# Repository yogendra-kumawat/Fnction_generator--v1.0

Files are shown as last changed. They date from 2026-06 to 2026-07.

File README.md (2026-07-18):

# ⚡ Function_generator v1.0 — Power & Control Board







> Battery-powered portable oscilloscope — power management, voltage regulation, user control interface board, and STM32-based firmware with real-time waveform generation and display.

---

## 📋 Overview

This project is a **portable open-source Function_generator** built around the STM32F103 microcontroller. It combines:

- Safe **Li-ion battery charging** from an external USB/DC source
- A clean **regulated voltage rail** for the microcontroller (MCU)
- **Control switches** for power on/off and user interaction
- Protection and filtering circuitry for stable operation
- **Real-time waveform generation** with adjustable frequency and duty cycle **{PWM ,DC,Square}->{working for sine,triangular,and oscilloscopic function}**
- **Dual-channel ADC signal acquisition** with interrupt-driven sampling
- **SSD1306 OLED display** with a multi-window navigation menu
- **FreeRTOS / CMSIS-OS2** multitasking firmware

---

## 🔲 System Block Diagram

```
┌─────────────┐     ┌──────────────┐     ┌─────────────┐
│  USB / DC   │────▶│  Battery     │────▶│  Li-ion /   │
│  Input (5V) │     │  Charger IC  │     │  LiPo Cell  │
└─────────────┘     └──────────────┘     └──────┬──────┘
                                                 │
                                                 ▼
                    ┌──────────────┐     ┌───────────────┐
                    │   STM32F103  │◀────│   Voltage     │
                    │   (MCU)      │     │   Regulator   │
                    └──────┬───────┘     └───────────────┘
                           │
          ┌────────────────┼────────────────┐
          ▼                ▼                ▼
   ┌─────────────┐  ┌────────────┐  ┌─────────────┐
   │ ADC1 / ADC2 │  │ TIM1 / TIM2│  │ SSD1306     │
   │ Signal In   │  │ PWM Out    │  │ OLED (I2C)  │
   └─────────────┘  └────────────┘  └─────────────┘
          ▲
   ┌─────────────┐
   │  Control    │
   │  Switches   │
   │ (EXTI GPIO) │
   └─────────────┘
```

---

## 🧩 Key Hardware Components

| Module | Function | Interface | Type |
|---|---|---|---|
| **Battery Charger IC** | CC/CV Li-ion charging; over-voltage & over-current protection | USB / DC jack | Power |
| **Li-ion / LiPo Cell** | Main energy storage; powers device off-grid | JST connector | Power |
| **Voltage Regulator** | Converts battery voltage to stable 3.3 V / 5 V for MCU | EN pin (switch-controlled) | Regulation |
| **Power Switch** | Hard on/off; drives regulator enable to cut standby draw | Mechanical toggle | Control |
| **Mode / Select Switch** | User input for menu navigation; connects to MCU GPIO via EXTI | MCU GPIO (EXTI2/3) | Control |
| **SSD1306 OLED** | 128×32 display for menus, waveform preview, freq & duty info | I2C (I2C1, 100 kHz) | Display |
| **Decoupling Capacitors** | Filters noise on power rails; stabilises regulator output | Inline on VCC / GND | Passive |

---

## ⚙️ Electrical Specifications

| Parameter | Value |
|---|---|
| Input Voltage | 5 V (USB / DC) |
| Battery Type | Li-ion / LiPo |
| Battery Voltage | 3.7 V nominal |
| Regulated Output | 3.3 V / 5 V |
| Max Charge Current | 500 mA (configurable) |
| MCU | STM32F103 @ 48 MHz (HSE × PLL ×6) |
| ADC Resolution | 12-bit (0–4095) |
| ADC Channels | ADC1 — CH0 (coarse), ADC2 — CH1 (fine) |
| PWM Output | TIM1 CH2 (variable freq + duty) |
| UART | USART1 @ 9600 baud |

---

## 🖥️ Firmware Architecture

The firmware runs on **FreeRTOS / CMSIS-OS2** with four concurrent tasks:

| Task | Priority | Role |
|---|---|---|
| `wave_gen` | Normal | Applies selected waveform output via `set_wave()` |
| `read_wave` | Normal | Reserved for signal acquisition / processing |
| `display` | Low | Drives SSD1306 OLED menu and waveform preview |
| `monitor` | Realtime | Polls ADC via interrupt, handles button EXTI events |

### Clock Configuration

```
HSE (external crystal)
  └──▶ PLL ×6 → 48 MHz SYSCLK
         ├── AHB  /1 → 48 MHz
         ├── APB1 /2 → 24 MHz  (TIM2, I2C)
         ├── APB2 /1 → 48 MHz  (TIM1, ADC)
         ├── ADC  /6 →  8 MHz
         └── USB      → 48 MHz (direct PLL)
```

---

## 📟 Display Menu System

The OLED display (`window` variable) has five screens:

| Window | Screen | Description |
|---|---|---|
| `0` | **Main Menu** | Scrollable list — Waves, Oscill., Port, PWM, Config |
| `1` | **Wave Select** | Choose waveform type: Sine, Ramp, Square, Noise, DC |
| `3` | **Port Select** | Choose output port: A or B |
| `4` | **PWM Control** | Live freq + duty cycle adjust with waveform preview |
| `5` | **Config** | Register/settings placeholder |

Navigation uses two buttons:
- **SELECT\_1** (`EXTI2`) — scroll / increment selection
- **SELECT\_2** (`EXTI3`) — confirm / enter submenu (toggle `select2`)
## display overview
WhatsApp Video 2026-06-03 at 1 54 03 PM
WhatsApp Video 2026-06-03 at 1 50 50 PM

---

## 🌊 PWM / Waveform Generation

`set_dynamic_frequency()` computes TIM1 prescaler and auto-reload register values at runtime to hit any target frequency from the 48 MHz timer clock:

```c
uint32_t total_divider = 48_000_000 / target_freq;
uint32_t psc = (total_divider - 1) / 65536;
uint32_t arr = (total_divider / (psc + 1)) - 1;
uint32_t pulse = (duty_cycle * (arr + 1)) / 100;
```

- **Frequency range:** ~1 Hz to ~47 MHz (capped at 47 MHz in MHz mode)
- **Duty cycle:** 0–100%, derived from ADC1 coarse potentiometer
- **Fine frequency:** derived from ADC2 fine potentiometer
- **Frequency units:** selectable — Hz / kHz / MHz (multipliers: ×1 / ×1000 / ×1 000 000)

---

## 🔍 How It Works

### 1 — Battery Charging

When a USB or DC supply is connected, based on feedback from charging battery the power is controlled ,basically turning off the power supply when battery is charged.

### 2 — Regulated Power to MCU

basically is is based on the voltage follower principle.

### 3 — Signal Acquisition (ADC)

Both ADC1 and ADC2 are started in **interrupt mode** (`HAL_ADC_Start_IT`) by the `monitor` task every 300 ms(also to control the bouncing effect of buttons so giving delay ). The `HAL_ADC_ConvCpltCallback` ISR:
- Reads the raw 12-bit value
- Tracks rolling **min / max** for dynamic range normalisation
- Toggles an indicator GPIO (`indi_Pin`) on every conversion

### 4 — Control Switches (EXTI)

`select_1_Pin` and `select_2_Pin` are configured as **falling-edge EXTI** inputs with internal pull-ups. The EXTI callback sets `flag_1` and wakes the `monitor` task via `osThreadFlagsSet`. The monitor task then increments `select1` (0–4) or `select2` (0–1) accordingly.

---

## 🚀 Getting Started

**Step 1 — Connect Battery**  
Connect a Li-ion / LiPo cell to the JST battery connector, observing polarity markings on the PCB silkscreen.

**Step 2 — (Optional) Charge**  
Connect a 5 V USB or DC supply. The onboard charging IC will manage the charge cycle automatically. The charge LED illuminates during active charging.

**Step 3 — Flash Firmware**  
Open the project in **STM32CubeIDE**{extract the file and arrange accordigly in stm ide as due to version conflicts the direct project will not work }.
see main.c file for full logic implementation

**Step 4 — Power On**  
Flip the power switch to **ON**. The voltage regulator enables, the MCU boots, and the OLED displays the main menu.

**Step 5 — Navigate**  
- Press **SELECT\_1** to scroll through menu items.
- Press **SELECT\_2** to enter a submenu.
- In **PWM mode** (Window 4): rotate the coarse pot (ADC1) to adjust duty cycle; rotate the fine pot (ADC2) to adjust frequency. Press SELECT\_1 to cycle Hz → kHz → MHz.

---

## 🛠️ Dependencies

| Dependency | Purpose |
|---|---|
| STM32CubeIDE / CubeMX | Project generation and build toolchain |
| STM32 HAL (F1 series) | Peripheral abstraction (ADC, TIM, I2C, UART, USB) |
| CMSIS-OS2 / FreeRTOS | RTOS kernel |
| `ssd1306` driver | I2C OLED display library (`ssd1306.h`, `ssd1306_fonts.h`) |{references->https://github.com/afiskon/stm32-ssd1306}

---

## 📄 License

This project is open source. See [`LICENSE`](./LICENSE) for details.

---

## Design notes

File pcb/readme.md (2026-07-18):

# 🟤 Function Generator v1.0 — PCB

## Board Specs

| Property | Value |
|---|---|
| Substrate | Single-sided FR2 copper-clad |
| Fabrication | Toner-transfer chemical etch|
| Copper layer | 1 (bottom) |
| Board size | (90x45 mm) |

<br>

---

## Toner Transfer Etch Process

1. Print copper layer (mirrored) 

2. Cut copper-clad board to size(90x45 mm), clean surface with fine sandpaper + acetone

3. Place paper face-down on copper, press firmly with clothes iron
   Temperature : ~180 °C
   Duration    : 5–7 minutes, firm even pressure, no sliding

4. Soak board in warm water for 2–3 minutes, peel paper slowly
   Toner remains bonded to copper as etch resist

5. Inspect under light — touch up any broken traces with a permanent marker

WhatsApp Image 2026-07-17 at 7 32 57 PM

6. Submerge in FeCl₃ (ferric chloride) solution
   Time : 15–30 min depending on solution temperature and
   stair the solution for fast etching

WhatsApp Video 2026-07-18 at 9 00 03 AM

7. Remove when all unprotected copper is dissolved — only traces remain

8. Rinse thoroughly, strip toner with acetone

WhatsApp Image 2026-07-17 at 7 25 27 PM

9. Dry, inspect continuity with multimeter
---

> **Tip:** Warm FeCl₃ (~40 °C) etches 2× faster and gives cleaner trace edges. A plastic container on a hot plate works fine.

<br>

---

## DIY Drill Rig

No PCB drill press — so one was built.

```
┌─────────────────────────┐
│   Servo Tester Module   │  ← Speed control via PWM knob
│   (blue box, blue LED)  │
└────────────┬────────────┘
             │ PWM signal
             ▼
   Brushless RC Motor
   (gold can, ~12 V)
             │
   Press-fit into PVC pipe  ← Acts as handle + rigidity
             │
   Keyless Mini Drill Chuck
             │
    0.8 mm Carbide Drill Bit
```

WhatsApp Image 2026-07-17 at 7 33 01 PM

<br>

---

## What's On the Board

### Power Section
- ams1117-adj — adjustable output regulator
- ams1117-5.0 — fixed 5 V
- AMS1117-3.3 — fixed 3.3 V
- Li-Ion charging IC (TP4056-style)
- DC barrel jack for external input

### Signal Section
- ADC input pin headers (2 channels, dual-simultaneous)
- 10 Ω on input limits current on accidental short — protects regulators from latch-up

### User Interface
- 4× tactile switches (6×6 mm)
- 2× trimmer potentiometers (10 kΩ)
- 1× green LED (power indicator)

### Connectors
- I²C header (GND / VCC / SCL / SDA) — for SSD1306 OLED
- extra I²C port for future use
- STM32 Blue Pill debugging wires via male pin headers
- other useful pin headers
<br>


<br>
WhatsApp Image 2026-07-17 at 7 25 34 PM
WhatsApp Image 2026-07-17 at 7 25 36 PM

---

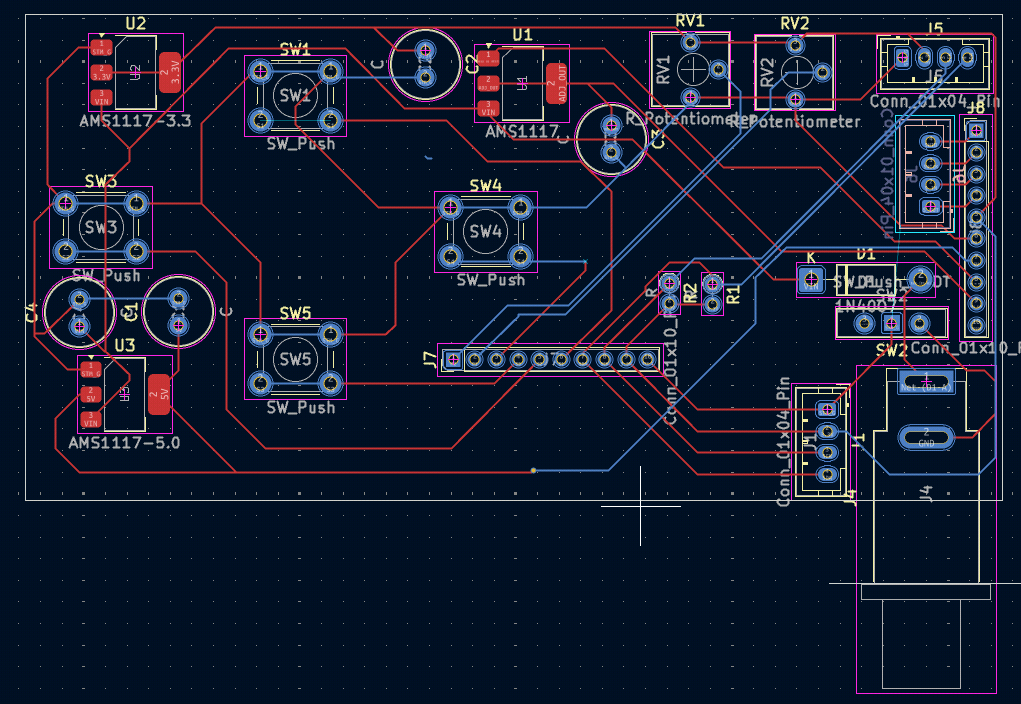
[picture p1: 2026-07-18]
pcb/pcb.png

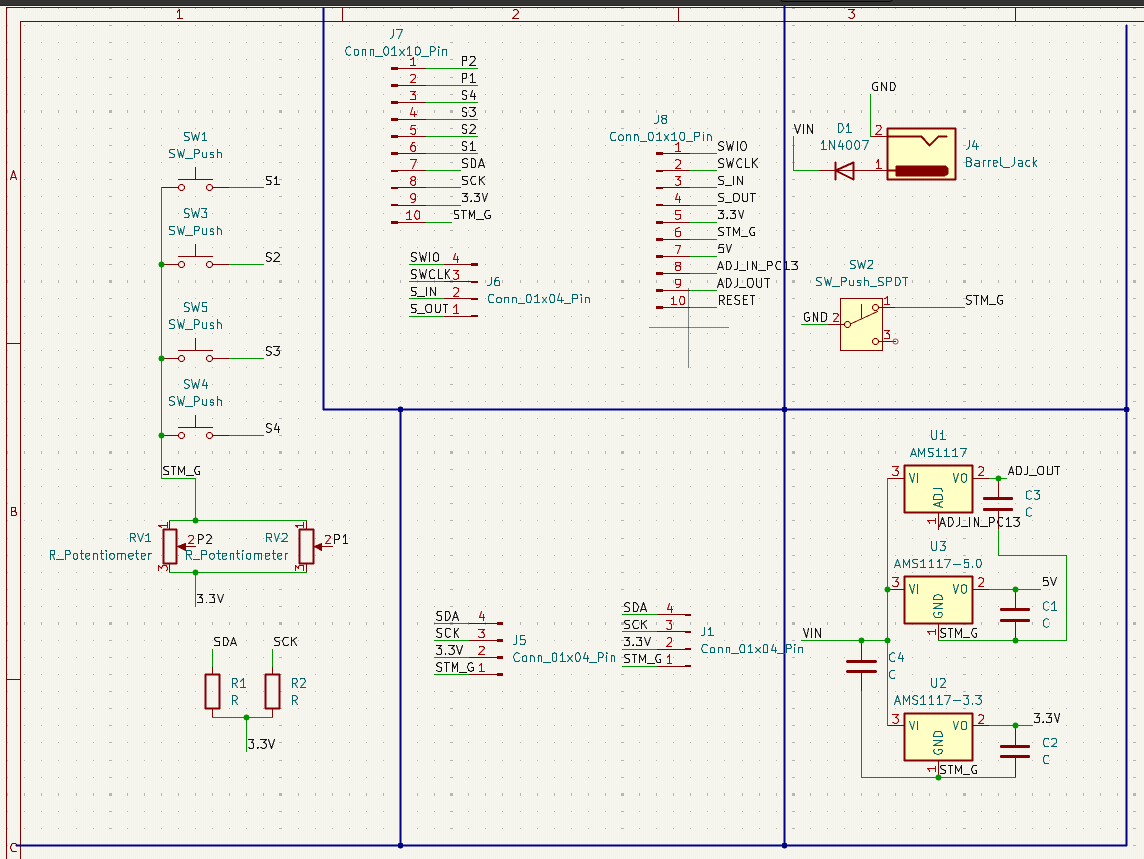
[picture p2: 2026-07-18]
pcb/sch.png

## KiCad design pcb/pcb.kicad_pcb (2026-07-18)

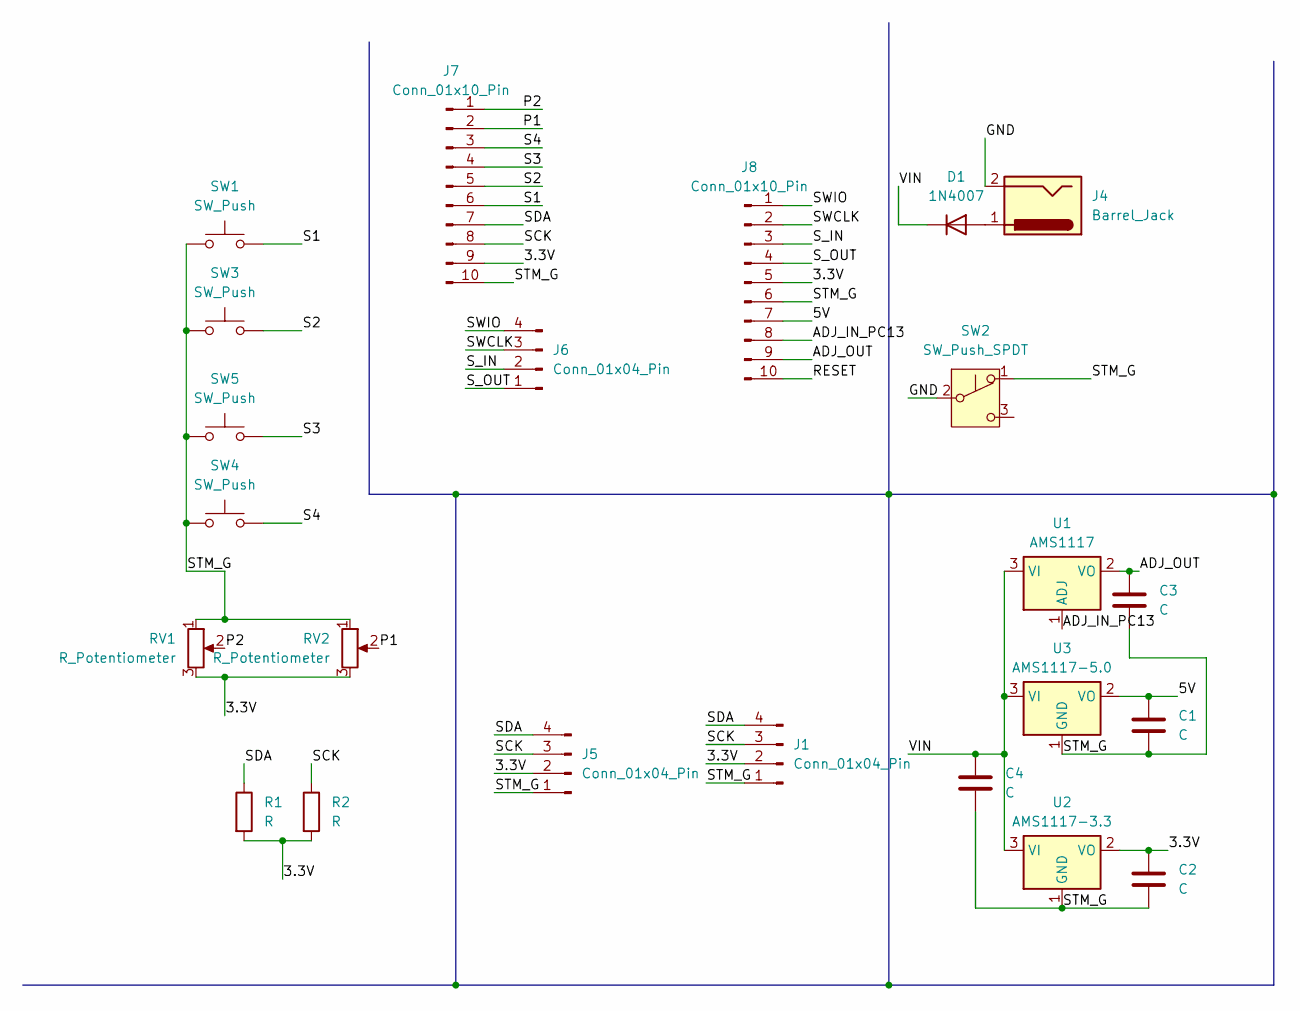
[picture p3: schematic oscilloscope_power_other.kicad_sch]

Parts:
C1, C2, C3, C4: C; C_Radial_D6.3mm_H11.0mm_P2.50mm
D1: 1N4007; D_DO-41_SOD81_P10.16mm_Horizontal
J1, J5, J6: Conn_01x04_Pin; JST_PH_B4B-PH-K_1x04_P2.00mm_Vertical
J4: Barrel_Jack; BarrelJack_SwitchcraftConxall_RAPC10U_Horizontal
J7, J8: Conn_01x10_Pin; PinHeader_1x10_P2.00mm_Vertical
R1, R2: R; R_Axial_DIN0204_L3.6mm_D1.6mm_P1.90mm_Vertical
RV1, RV2: R_Potentiometer; Potentiometer_Vishay_T73YP_Vertical
SW1, SW3, SW4, SW5: SW_Push; SW_PUSH-12mm
SW2: SW_Push_SPDT; SW_Slide-03_Wuerth-WS-SLTV_10x2.5x6.4_P2.54mm
U1: AMS1117; SOT-223-3_TabPin2
U2: AMS1117-3.3; SOT-223-3_TabPin2
U3: AMS1117-5.0; SOT-223-3_TabPin2

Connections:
/3.3V: C2.1, J1.2, J5.2, J7.9, J8.5, R1.2, R2.2, RV1.3, RV2.3, U2.2 (VO)
/5V: C1.1, J8.7, U3.2 (VO)
/ADJ_IN_PC13: J8.8, U1.1 (ADJ)
/ADJ_OUT: C3.1, J8.9, U1.2 (VO)
/GND: J4.2, SW2.2 (B)
/P1: J7.2, RV2.2
/P2: J7.1, RV1.2
/RESET: J8.10
/S1: J7.6, SW1.2
/S2: J7.5, SW3.2
/S3: J7.4, SW5.2
/S4: J7.3, SW4.2
/SCK: J1.3, J5.3, J7.8, R2.1
/SDA: J1.4, J5.4, J7.7, R1.1
/STM_G: C1.2, C2.2, C3.2, C4.2, J1.1, J5.1, J7.10, J8.6, RV1.1, RV2.1, SW1.1, SW2.1 (A), SW3.1, SW4.1, SW5.1, U2.1 (GND), U3.1 (GND)
/SWCLK: J6.3, J8.2
/SWIO: J6.4, J8.1
/S_IN: J6.2, J8.3
/S_OUT: J6.1, J8.4
/VIN: C4.1, D1.1 (K), U1.3 (VI), U2.3 (VI), U3.3 (VI)
unnamed: D1.2 (A), J4.1

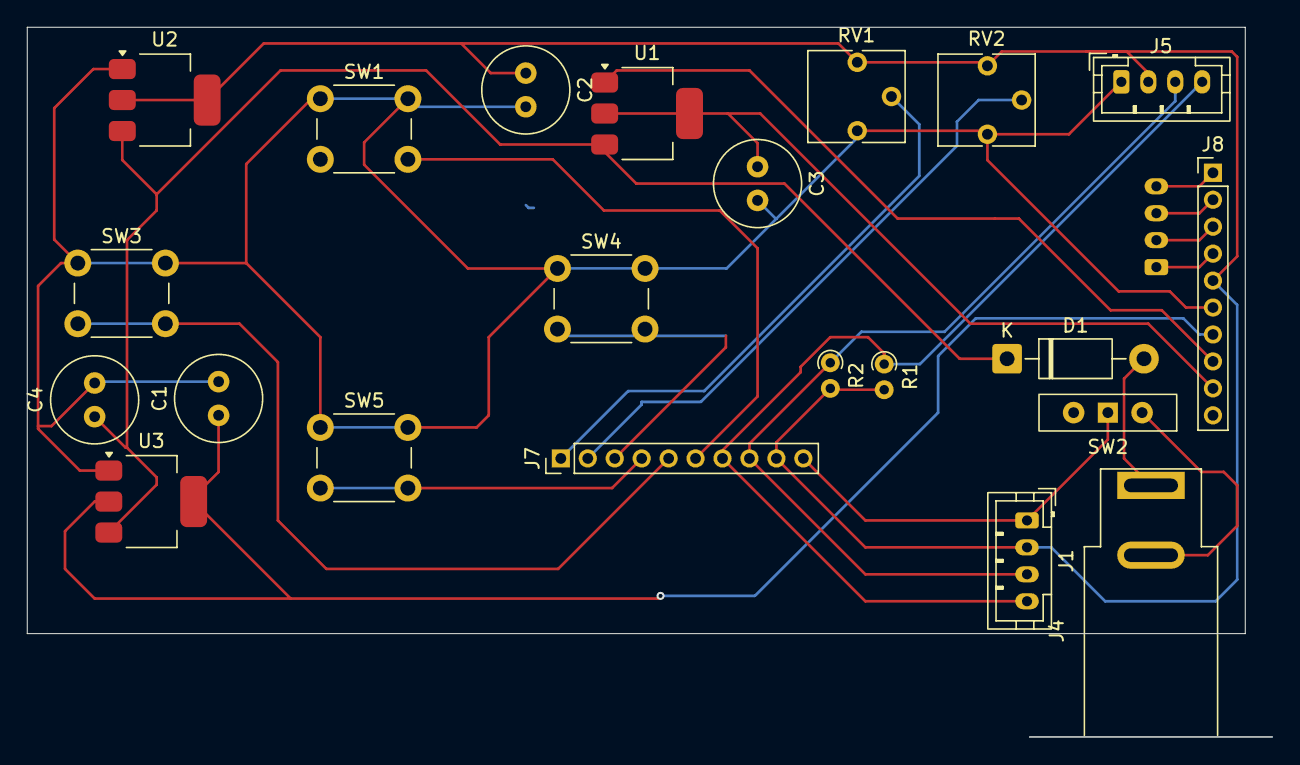
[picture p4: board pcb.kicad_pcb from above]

Board: 2 copper layers, 90.4 x 45.0 mm, 23 parts (1 on the bottom side), 20 nets.

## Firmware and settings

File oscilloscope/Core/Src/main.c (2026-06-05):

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
/* Includes ------------------------------------------------------------------*/
#include "main.h"
#include "cmsis_os.h"

/* USER CODE BEGIN Includes */
#include<stdio.h>
#include "ssd1306.h"
#include "ssd1306_fonts.h"
volatile int raw_adc_value1=0;
volatile int raw_adc_value2=0;
uint8_t select1=0;
uint8_t select2=0;
 int fine_max=1;
 int fine_min=9999;
int value_max=1;
 int value_min=9999;
volatile int freq=0;
uint8_t flag_1=0;
uint8_t window=5;
int duty_cycle=80;
  char freq_text[10];
  char duty_cyc[5];
int port=0;
int pwm_log=0;
char slp[5];
int edit=0;
char channel='T';
uint8_t ch_assig=0;
const uint8_t sine_wave[40] = {
    10, 12, 13, 15, 16, 17, 18, 19, 20, 20,
    20, 20, 20, 19, 18, 17, 16, 15, 13, 12,
    10,  8,  7,  5,  4,  3,  2,  1,  0,  0,
     0,  0,  0,  1,  2,  3,  4,  5,  7,  8
};
/* USER CODE END Includes */

ADC_HandleTypeDef hadc1;
ADC_HandleTypeDef hadc2;

I2C_HandleTypeDef hi2c1;

TIM_HandleTypeDef htim1;
TIM_HandleTypeDef htim2;

UART_HandleTypeDef huart1;

PCD_HandleTypeDef hpcd_USB_FS;

/* Definitions for wave_gen */
osThreadId_t wave_genHandle;
const osThreadAttr_t wave_gen_attributes = {
  .name = "wave_gen",
  .stack_size = 128 * 4,
  .priority = (osPriority_t) osPriorityNormal,
};
/* Definitions for read_wave */
osThreadId_t read_waveHandle;
const osThreadAttr_t read_wave_attributes = {
  .name = "read_wave",
  .stack_size = 128 * 4,
  .priority = (osPriority_t) osPriorityNormal,
};
/* Definitions for display */
osThreadId_t displayHandle;
const osThreadAttr_t display_attributes = {
  .name = "display",
  .stack_size = 128 * 4,
  .priority = (osPriority_t) osPriorityLow,
};
/* Definitions for monitor */
osThreadId_t monitorHandle;
const osThreadAttr_t monitor_attributes = {
  .name = "monitor",
  .stack_size = 128 * 4,
  .priority = (osPriority_t) osPriorityRealtime,
};
/* USER CODE BEGIN PV */

void set_dynamic_frequency(uint32_t target_freq ,int duty)
{
    if (target_freq == 0) return;

    uint32_t timer_clock = 48000000; // 48 MHz base clock
    uint32_t total_divider = timer_clock / target_freq;
    uint32_t psc = (total_divider - 1) / 65536;

     uint32_t arr = (total_divider / (psc + 1)) - 1;

     __HAL_TIM_SET_PRESCALER(&htim1, psc);
    __HAL_TIM_SET_AUTORELOAD(&htim1, arr);

    uint32_t dynamic_pulse = (duty * (arr + 1)) /100;
    __HAL_TIM_SET_COMPARE(&htim1, TIM_CHANNEL_2, dynamic_pulse);
}
//getting control signal using interrupts

void HAL_ADC_ConvCpltCallback(ADC_HandleTypeDef* hadc)
{
    if(hadc->Instance == ADC1)
    {
    	raw_adc_value1 = HAL_ADC_GetValue(&hadc1);
    	 		          if (value_max<raw_adc_value1)
    	 		        	 value_max=raw_adc_value1;
    	 		         if (value_min>raw_adc_value1)
    						 value_min=raw_adc_value1;
    }
    else if (hadc->Instance==ADC2)

    { raw_adc_value2 = HAL_ADC_GetValue(&hadc2);
	   if (fine_max<raw_adc_value2)
				 fine_max=raw_adc_value2;
			 if (fine_min>raw_adc_value2)
				 fine_min=raw_adc_value2;

 }
    HAL_GPIO_TogglePin(GPIOC, indi_Pin);

}
void  HAL_GPIO_EXTI_Callback(uint16_t select_1){
	if (select_1==select_1_Pin){
flag_1=1;}
else if (select_1==select_2_Pin){
	flag_1=2;}
	edit=1;
	osThreadFlagsSet(monitorHandle, 0x01);

}



// all control signal geted

void set_wave(int freq,int channel)
{
    switch (channel){
	case 1:
	    __HAL_TIM_SET_COMPARE(&htim1, TIM_CHANNEL_1, freq);
	    break;
	case 2:
		__HAL_TIM_SET_COMPARE(&htim2, TIM_CHANNEL_1, freq);
		break;
      }
}




/* USER CODE END PV */

void SystemClock_Config(void);
static void MX_GPIO_Init(void);
static void MX_ADC1_Init(void);
static void MX_I2C1_Init(void);
static void MX_TIM1_Init(void);
static void MX_TIM2_Init(void);
static void MX_USART1_UART_Init(void);
static void MX_USB_PCD_Init(void);
static void MX_ADC2_Init(void);
void start_wave_gen(void *argument);
void StartRead(void *argument);
void StartDisplay(void *argument);
void StartMonitor(void *argument);

/**
  * @brief  The application entry point.
  * @retval int
  */
int main(void)
{

  /* MCU Configuration--------------------------------------------------------*/

  /* Reset of all peripherals, Initializes the Flash interface and the Systick. */
  HAL_Init();

  /* Configure the system clock */
  SystemClock_Config();

  /* Initialize all configured peripherals */
  MX_GPIO_Init();
  MX_ADC1_Init();
  MX_I2C1_Init();
  MX_TIM1_Init();
  MX_TIM2_Init();
  MX_USART1_UART_Init();
  MX_USB_PCD_Init();
  MX_ADC2_Init();
  /* USER CODE BEGIN 2 */
  HAL_ADCEx_Calibration_Start(&hadc1);
    HAL_ADCEx_Calibration_Start(&hadc2);
    HAL_TIM_PWM_Start(&htim1, TIM_CHANNEL_2);
  /* USER CODE END 2 */

  /* Init scheduler */
  osKernelInitialize();

  /* USER CODE BEGIN RTOS_MUTEX */
  /* add mutexes, ... */

  /* USER CODE END RTOS_MUTEX */

  /* USER CODE BEGIN RTOS_SEMAPHORES */
  /* add semaphores, ... */
  /* USER CODE END RTOS_SEMAPHORES */

  /* USER CODE BEGIN RTOS_TIMERS */
  /* start timers, add new ones, ... */
  /* USER CODE END RTOS_TIMERS */

  /* USER CODE BEGIN RTOS_QUEUES */
  /* add queues, ... */
  /* USER CODE END RTOS_QUEUES */

  /* Create the thread(s) */
  /* creation of wave_gen */
  wave_genHandle = osThreadNew(start_wave_gen, NULL, &wave_gen_attributes);

  /* creation of read_wave */
  read_waveHandle = osThreadNew(StartRead, NULL, &read_wave_attributes);

  /* creation of display */
  displayHandle = osThreadNew(StartDisplay, NULL, &display_attributes);

  /* creation of monitor */
  monitorHandle = osThreadNew(StartMonitor, NULL, &monitor_attributes);

  /* USER CODE BEGIN RTOS_THREADS */
  /* add threads, ... */
  /* USER CODE END RTOS_THREADS */

  /* USER CODE BEGIN RTOS_EVENTS */
  /* add events, ... */
  /* USER CODE END RTOS_EVENTS */

  /* Start scheduler */
  osKernelStart();

  /* We should never get here as control is now taken by the scheduler */

  /* Infinite loop */
  /* USER CODE BEGIN WHILE */
  while (1)
  {
    /* USER CODE END WHILE */

    /* USER CODE BEGIN 3 */
  }
  /* USER CODE END 3 */
}

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
/* USER CODE BEGIN Header_start_wave_gen */
/**
  * @brief  Function implementing the wave_gen thread.
  * @param  argument: Not used
  * @retval None
  */
/* USER CODE END Header_start_wave_gen */
void start_wave_gen(void *argument)
{
  /* USER CODE BEGIN 5 */
  /* Infinite loop */
  for(;;)
  {

	  if (select1==1)
		  if (select1==1||select1==2)
	  set_wave(freq,select1);
    osDelay(1);
  }
  /* USER CODE END 5 */
}

/* USER CODE BEGIN Header_StartRead */
/**
* @brief Function implementing the read_wave thread.
* @param argument: Not used
* @retval None
*/
/* USER CODE END Header_StartRead */
void StartRead(void *argument)
{
  /* USER CODE BEGIN StartRead */
  /* Infinite loop */
  for(;;)
  {
    osDelay(1);
  }
  /* USER CODE END StartRead */
}

/* USER CODE BEGIN Header_StartDisplay */
/**
* @brief Function implementing the display thread.
* @param argument: Not used
* @retval None
*/
/* USER CODE END Header_StartDisplay */
void StartDisplay(void *argument)
{
  /* USER CODE BEGIN StartDisplay */
	ssd1306_Init();
	char wave_menu[5][9]={"Sine","Triangle","Square","Noise","Dc"};
	char menu[5][7]={"Waves","oscill.","port","pwm","config"};
	char ffreq[3][4]={"Hz","Khz","Mhz"};
	int freq_mul[3]={1,1000,1000000};
	char ports[2][2]={"A","B"};

  /* Infinite loop */

	  int scroll=0,temp=0;

   for(;;)
  {
	  if (scroll==0 && select2==1){
	 	  		  window=1;
	 	  	  }
	  if (scroll==1 && select2==1){
	 	 	  		  window=2;
	 	 	  	  }
	  if (scroll==2 && select2==1){
		  window=3;
	  }
	  if (scroll==3 && select2==1){
		  window=4;
	  }
	  if (scroll==4 && select2==1){
		  window=5;
	  }
	  if (ch_assig&&window!=3){
	  	  		if (select1==1)
	  			  channel='B';
	  	    else
	  			  channel='A';
	  	  	}
	  ch_assig=0;
	  duty_cycle=raw_adc_value1*100/(value_max-value_min);//100/(value_max-value_min)*
	  freq=raw_adc_value2*1000/(fine_max-fine_min);
	  sprintf(freq_text, "%d", freq );
	  sprintf(duty_cyc, "%d", duty_cycle);//
	  ssd1306_Fill(Black);
		 ssd1306_Line(80, 0, 80, 31, White);
		 ssd1306_Line(20, 0, 20, 31, White);
		 ssd1306_Line(0, 19, 20, 19, White);

if (pwm_log){
	ssd1306_SetCursor(2, 22);
	  ssd1306_WriteString("pwm",  Font_6x8, White);
}
else {
	ssd1306_SetCursor(1, 0);
		 		  ssd1306_WriteChar('A',  Font_6x8, White);
		 		 ssd1306_SetCursor(2, 11);
				ssd1306_WriteChar('B',  Font_6x8, White);
		 ssd1306_SetCursor(3, 22);
		  ssd1306_WriteString(";)",  Font_7x10, White);
	 ssd1306_Line(0, 9, 20, 9, White);
	 if (channel=='A'){
	ssd1306_FillRectangle(0, 0,20,9, White);
	ssd1306_SetCursor(1, 0);
		  ssd1306_WriteString("A",  Font_6x8, Black);}
	 if (channel=='B'){
			ssd1306_FillRectangle(0, 9,20,20, White);
			ssd1306_SetCursor(2, 11);
		  	ssd1306_WriteString("B",  Font_6x8, Black);
	 }

}


	  if (window==0){
		  scroll=select1;
		  if (select1<3)
	  	  temp=select1;
	  	 for(int i=0;i<3;i++){
	  				 ssd1306_SetCursor(85, i*10+2);
	  				  ssd1306_WriteString(menu[i+select1-temp],  Font_6x8, White);
	  			 }
	  	 	    	ssd1306_FillRectangle(80, temp*10, 128, (scroll+1)*10, White);
	  		  	  ssd1306_SetCursor(85, temp*10+2);
	  		  	  ssd1306_WriteString(menu[select1],  Font_6x8, Black);
	  }

	  	  if (window==1){

	  		if (select2==0)
	  	  window=0;
	  		if (select1<3)
			  temp=select1;
//	  		int sst=select1;
//	  		if (select1==3)
//	  			sst=2;
	  		for(int i=0;i<3;i++){
	  					 ssd1306_SetCursor(22, i*10+2);
	  					  ssd1306_WriteString(wave_menu[i+select1-temp],  Font_6x8, White);
	  				 }
	  				ssd1306_FillRectangle(20, temp*10, 80, (select1+1)*10, White);
	  				ssd1306_SetCursor(22, temp*10+2);
	  				ssd1306_WriteString(wave_menu[select1],  Font_6x8, Black);
	  		if (select1==0)
	  		{for(int i=85;i<125;i++){
	  			ssd1306_DrawPixel(i, sine_wave[i-85],White);
	  		}}
	  		if (select1==1){
		  		int slope=raw_adc_value1*100/(value_max-value_min)-50;
		  		int temp=1;
		  		if (slope<0)
		  			temp=-1;
		  		sprintf(slp,"%d.%d",slope/10,temp*slope%10);
		  		int j=0;
	  			int mul=-1;
	  			for (int i=0;i<40;i++){
	  				if (i%10==0)
	  					mul=mul*-1;
	  				if (mul==-1)
	  					j--;
	  				else j++;
	  				ssd1306_SetCursor(85, 1);
	  				ssd1306_WriteString("S=", Font_6x8, White);
	  				ssd1306_SetCursor(99, 1);
					ssd1306_WriteString(slp, Font_6x8, White);
 					 ssd1306_DrawPixel(i+85, slope*j/10+20, White);

	  			}
	  		}
	  		if (select1==2){
	  			ssd1306_Line(95, 1, 95, 16, White);
				ssd1306_Line(125, 1, 125, 16, White);
				ssd1306_Line(110, 1, 110, 16,White);
				ssd1306_Line(95,1,110,1,White);
				ssd1306_Line(110,16,125,16,White);
				ssd1306_SetCursor(85, 22);
				ssd1306_WriteString("F=", Font_6x8, White);
				ssd1306_SetCursor(99, 22);
				ssd1306_WriteString(freq_text, Font_6x8, White);
		  		set_dynamic_frequency(freq*freq_mul[select1],duty_cycle);
	  		}
	  		if (select1==4){
	  			ssd1306_Line(95, 22, 125, 22, White);
		  		set_dynamic_frequency(100,100);//thinking that 100 % duty cycle means always high maze maze ke liye 100 hz
	  			//	  			edit=0;
//	  			char message[]="use PWM for this  ";
//	  			int j=0;
//	  			int cct=0;
//	  			while(message[j+cct]!='\0'){
//	  				if (edit==1)
//	  					break;
//	  				j++;
//	  				if (j==6){
//			  	 		 ssd1306_UpdateScreen();
//	  					j=0;
//	  					cct++;
//	  				}
//		  			ssd1306_SetCursor(85+j*6, 10);
//		  			ssd1306_WriteChar(message[j+cct], Font_6x8, White);
//		  			osDelay(15);
//	  			}




	  	  }
	  	  }
	  	  if (window==2){
	  		  window=0;

	  	  }
	  	if (window==3){
				if (select2==0)
			  window=0;
				if (select1>1)
					select1=0;
			for(int i=0;i<2;i++){
			 ssd1306_SetCursor(22, i*10+2);
			  ssd1306_WriteString(ports[i],  Font_6x8, White);
			 }
			ssd1306_FillRectangle(20, select1*10, 80, (select1+1)*10, White);
			port=select1;
			  ssd1306_SetCursor(22, select1*10+2);
			  ssd1306_WriteString(ports[select1],  Font_6x8, Black);
			 ch_assig=1;

	  		  	  }

	  	if (window==4){
	  		pwm_log=1;
	  		if (select2==0){
	  			  	  window=0;
	  			  	  pwm_log=0;
	  		}

	  			  ssd1306_SetCursor(1,9);
				  ssd1306_WriteString(ffreq[select1],  Font_6x8, White);


	  		if (select1==3)
					select1=0;
	  			if (select1==2)
					if (freq>47)
				freq=47;

	  		set_dynamic_frequency(freq*freq_mul[select1],duty_cycle);

	  	ssd1306_Line(25, 5, 25, 20, White);
	  	ssd1306_Line(75, 5, 75, 20, White);
	  	ssd1306_Line(50*duty_cycle/100+25, 5, 50*duty_cycle/100+25, 20,White);
	  	ssd1306_Line(25,5,50*duty_cycle/100+25,5,White);
	  	ssd1306_Line(50*duty_cycle/100+25,20,75,20,White);
	  	ssd1306_SetCursor(85,1);
	    ssd1306_WriteString("Freq.=  ",  Font_6x8, White);
	  	ssd1306_SetCursor(85,9);
	    ssd1306_WriteString(freq_text,  Font_6x8, White);
	  	ssd1306_Line(80, 17, 128, 17, White);
	  	ssd1306_SetCursor(85,20);
	  	ssd1306_WriteString("Dt=",  Font_6x8, White);
	  	ssd1306_SetCursor(105,20);
	  	ssd1306_WriteString(duty_cyc,  Font_6x8, White);

	  	}
	  	if (window==5){
	  		if (select2==0)
				  window=0;
	  		ssd1306_SetCursor(25,2);
	  		ssd1306_WriteString("select_reg",  Font_6x8, White);

	  	}
 		 ssd1306_UpdateScreen();

  }
  /* USER CODE END StartDisplay */
}

/* USER CODE BEGIN Header_StartMonitor */
/**
* @brief Function implementing the monitor thread.
* @param argument: Not used
* @retval None
*/
/* USER CODE END Header_StartMonitor */
void StartMonitor(void *argument)
{
  /* USER CODE BEGIN StartMonitor */
  /* Infinite loop */
  for(;;)
 {

	  HAL_ADC_Start_IT(&hadc1);
	  osDelay(300);
  HAL_ADC_Start_IT(&hadc2);

	  osThreadFlagsWait(0x01, osFlagsWaitAny,10);
	  if (flag_1==1){
		  select1++;
		  if (select1==5)
			  select1=0;
	  }
	  if (flag_1==2){
	  		  select2++;
	  		  if (select2==2)
	  			  select2=0;
	  	  }


	  flag_1=0;
    osThreadFlagsClear(0x01);
  }
  /* USER CODE END StartMonitor */
}

/**
  * @brief  Period elapsed callback in non blocking mode
  * @note   This function is called  when TIM3 interrupt took place, inside
  * HAL_TIM_IRQHandler(). It makes a direct call to HAL_IncTick() to increment
  * a global variable "uwTick" used as application time base.
  * @param  htim : TIM handle
  * @retval None
  */
void HAL_TIM_PeriodElapsedCallback(TIM_HandleTypeDef *htim)
{
  if (htim->Instance == TIM3) {
    HAL_IncTick();
  }
}

/**
  * @brief  This function is executed in case of error occurrence.
  * @retval None
  */
void Error_Handler(void)
{
  /* USER CODE BEGIN Error_Handler_Debug */
  /* User can add his own implementation to report the HAL error return state */
  __disable_irq();
  while (1)
  {
  }
  /* USER CODE END Error_Handler_Debug */
}

#ifdef  USE_FULL_ASSERT
/**
  * @brief  Reports the name of the source file and the source line number
  *         where the assert_param error has occurred.
  * @param  file: pointer to the source file name
  * @param  line: assert_param error line source number
  * @retval None
  */
void assert_failed(uint8_t *file, uint32_t line)
{
  /* USER CODE BEGIN 6 */
  /* User can add his own implementation to report the file name and line number,
     ex: printf("Wrong parameters value: file %s on line %d\r\n", file, line) */
  /* USER CODE END 6 */
}
#endif /* USE_FULL_ASSERT */

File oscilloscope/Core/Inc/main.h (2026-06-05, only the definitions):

#define indi_Pin GPIO_PIN_13
#define indi_GPIO_Port GPIOC
#define select_1_Pin GPIO_PIN_2
#define select_1_GPIO_Port GPIOA
#define select_1_EXTI_IRQn EXTI2_IRQn
#define select_2_Pin GPIO_PIN_3
#define select_2_GPIO_Port GPIOA
#define select_2_EXTI_IRQn EXTI3_IRQn
#define signal_2_Pin GPIO_PIN_4
#define signal_2_GPIO_Port GPIOA
#define signal_3_Pin GPIO_PIN_5
#define signal_3_GPIO_Port GPIOA
#define sig_out_3_Pin GPIO_PIN_6
#define sig_out_3_GPIO_Port GPIOA
#define select_2A7_Pin GPIO_PIN_7
#define select_2A7_GPIO_Port GPIOA
#define swdio_Pin GPIO_PIN_13
#define swdio_GPIO_Port GPIOB
#define rxd_Pin GPIO_PIN_14
#define rxd_GPIO_Port GPIOB
#define txd_Pin GPIO_PIN_15
#define txd_GPIO_Port GPIOB
#define sig_out_2_Pin GPIO_PIN_15
#define sig_out_2_GPIO_Port GPIOA

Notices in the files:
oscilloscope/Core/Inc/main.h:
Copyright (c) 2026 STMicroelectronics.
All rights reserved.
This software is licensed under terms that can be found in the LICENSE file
